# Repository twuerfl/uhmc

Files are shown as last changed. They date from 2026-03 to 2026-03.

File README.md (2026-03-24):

# UHMC – Underfloor Heating Manifold Controller

**UHMC** (Underfloor Heating Manifold Controller) is a modular, ESP32-based controller designed for precise regulation of underfloor heating circuits. It integrates advanced control features while remaining cost-efficient and flexible for home automation setups.

---

## Features

- **Microcontroller:** ESP32-WROOM-32E
- **Connectivity:**
  - Ethernet via LAN8720A **OR** WIFI
  - Optional USB via CP2102N (default not populated to reduce cost)
- **Heating Circuit Control:**
  - 12 heating circuits (loops) total
  - Circuits 11 and 12 share two outputs for double current capacity
- **Driver Hardware:**
  - 2 × TPL7407LAPW motor drivers
  - Each driven via a SN74HC595PWR shift register
- **I²C Expansion:**
  - TCA9548AMRGER I²C multiplexer
  - Supports 8 separate I²C inputs
- **Firmware:** ESPHome

---

## Hardware Overview

| Component | Purpose |
|---|---|
| ESP32-WROOM-32E | Main controller |
| LAN8720A | Ethernet interface |
| CP2102N | Optional USB for programming/debugging |
| TPL7407LAPW | 7-channel motor drivers for valve actuation |
| SN74HC595PWR | Shift registers to extend GPIOs for TPL7407LAPW |
| TCA9548AMRGER | I²C multiplexer for up to 8 I²C inputs |

---

## System Architecture
ESP32

->  SN74HC595  ->   TPL7407LAPW  ->  Heating Circuits 1-12

->  TCA9548AM  ->   I²C Sensors

->  LAN8720A   ->   Ethernet

->  CP2102N    ->   Optional USB

- Heating circuits 11 and 12 are paralleled for higher current capacity.
- ESPHome handles PID control, sensor input, and automation integration.

---

## Features in ESPHome

- Supports up to 12 heating circuits with PWM control
- I²C sensor integration via TCA9548 multiplexer
- Optional integration with Home Assistant
- Ethernet connectivity for remote monitoring and updates
- Modular configuration allowing flexible re-assignment of heating circuits

---

## License

CC BY-NC-SA 4.0
https://creativecommons.org/licenses/by-nc-sa/4.0/

---

## Notes

- USB interface is optional to save cost; populated only if needed.
- Firmware is configured via ESPHome YAML files for easy customization.

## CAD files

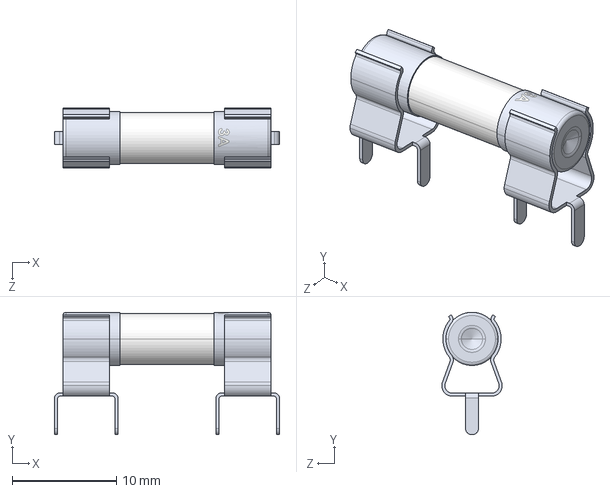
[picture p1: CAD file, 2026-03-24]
step/Fuse Holder.STEP
21.6 x 11.8 x 5.80 mm
Fuse Clip x 2
3A Fuse

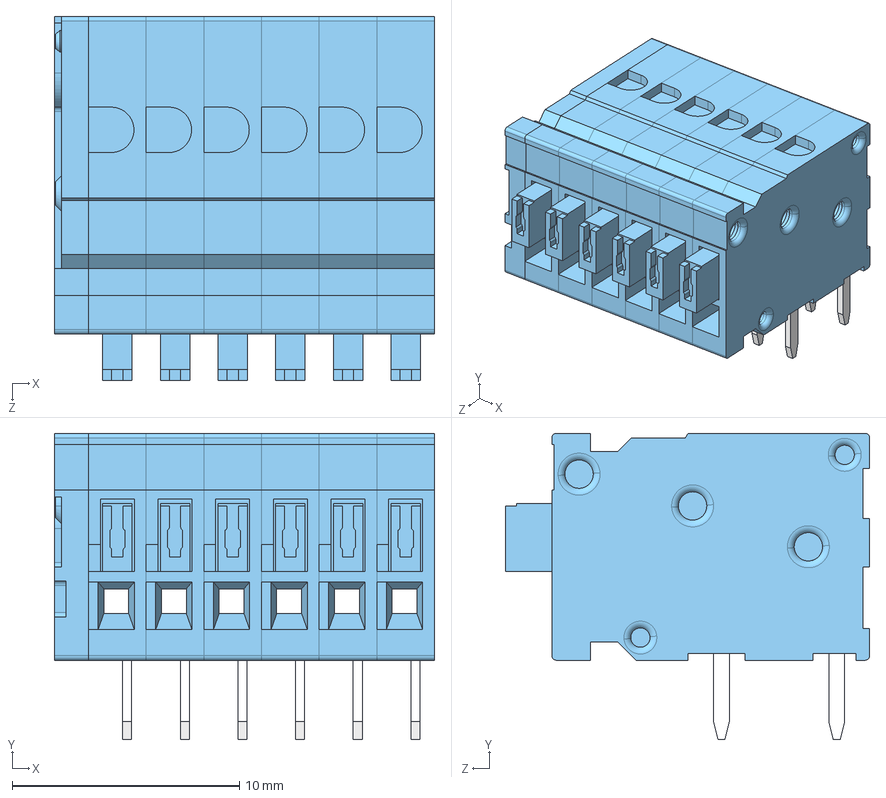
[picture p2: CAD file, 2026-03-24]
step/TBL009-254-06BE-2BE.step
16.7 x 13.5 x 16.1 mm
TBL009-254 - END CAP_Blue
TBL009-254 - BODY_Blue x 6
TBL009-254 - PUSH BUTTON_Blue x 6

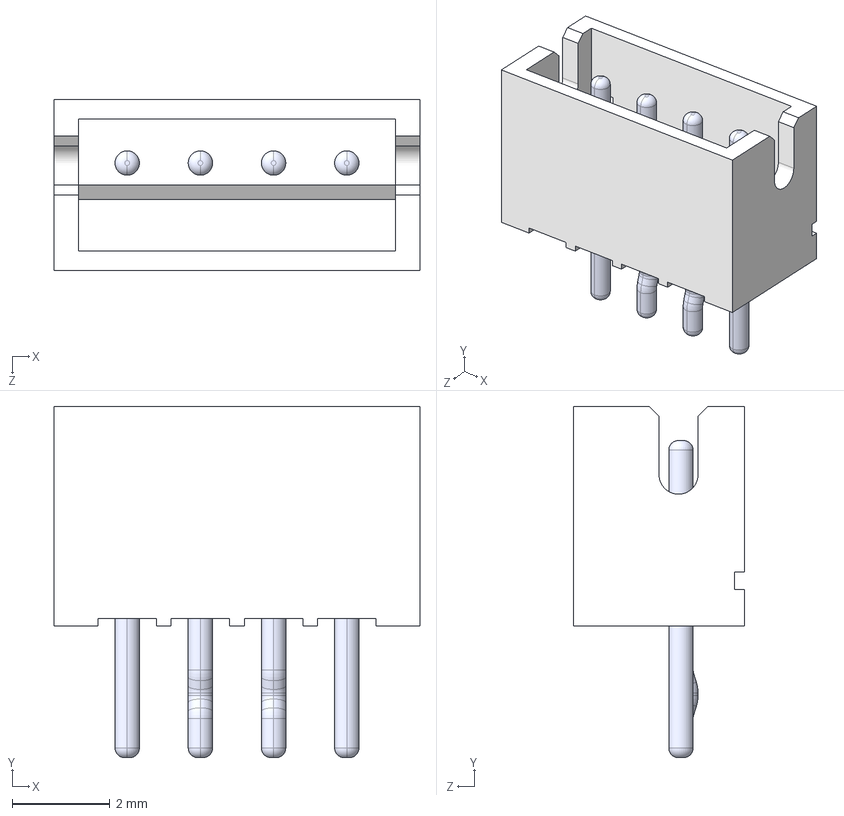
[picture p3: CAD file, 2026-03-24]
step/B4B-ZR--3DModel-STEP-56544.STEP
7.50 x 7.20 x 3.50 mm
BxB-ZR_4
pin_straight x 2
pin_Bent x 2

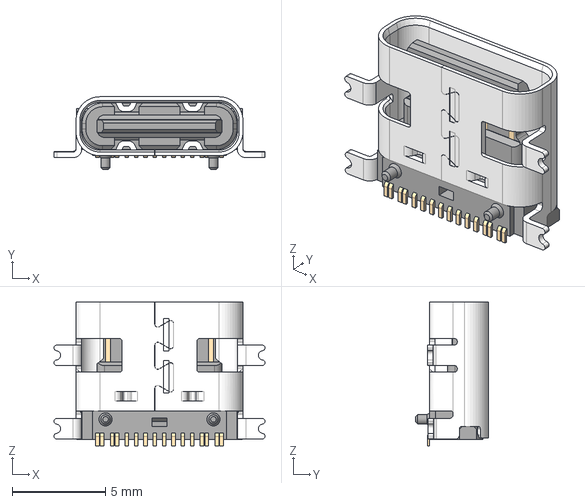
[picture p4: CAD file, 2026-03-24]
step/USB_C_Receptacle_GCT_USB4110.step
11.3 x 3.89 x 7.70 mm

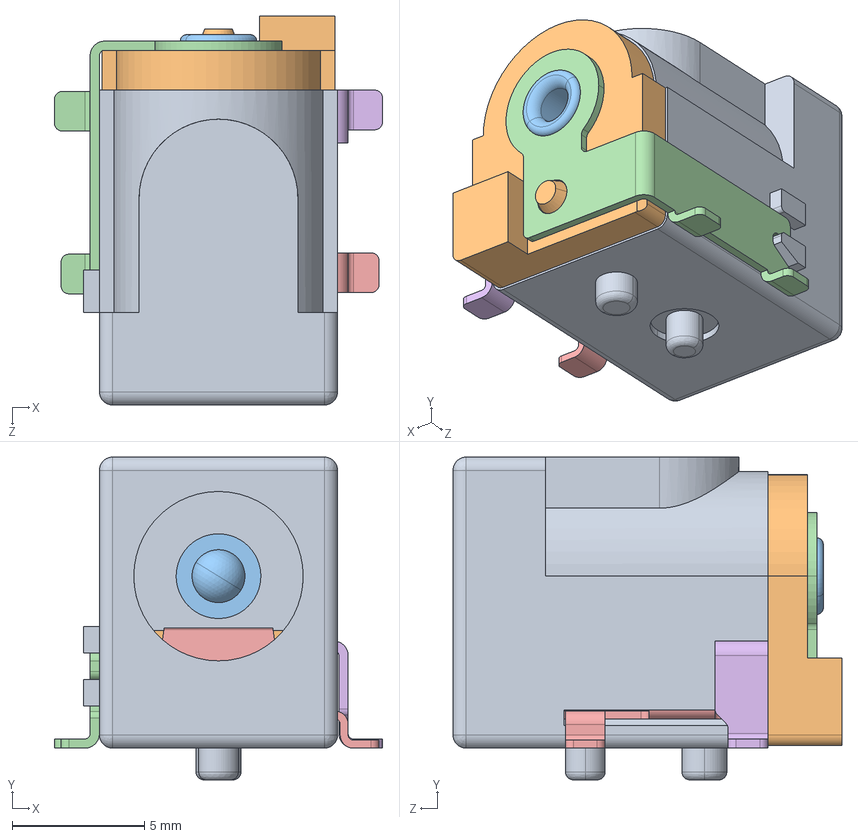
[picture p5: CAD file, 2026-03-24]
step/54-00164.STEP
12.4 x 12.2 x 14.7 mm
54-00164_shell
54-00164_insulator
54-00164_center
54-00164_center contact
54-00164_spring contact
54-00164_shell contact

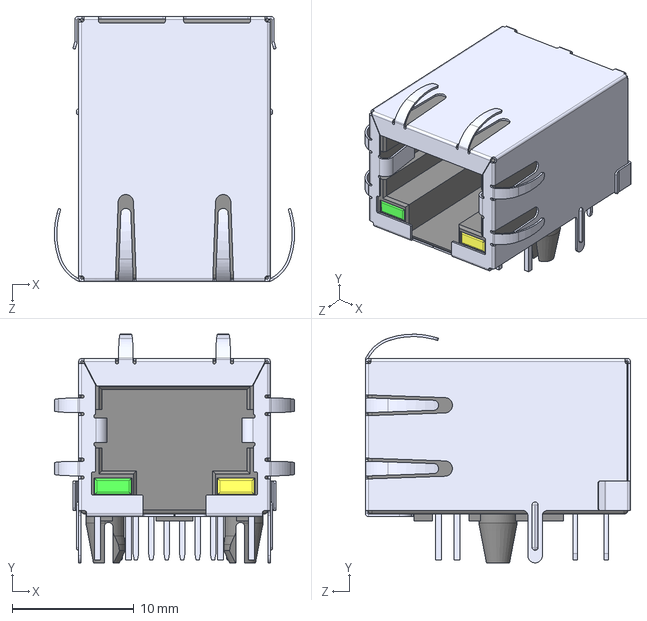
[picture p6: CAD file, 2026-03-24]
step/RJ45_Amphenol_RJMG1BD3B8K1ANR.step
19.7 x 18.8 x 21.8 mm

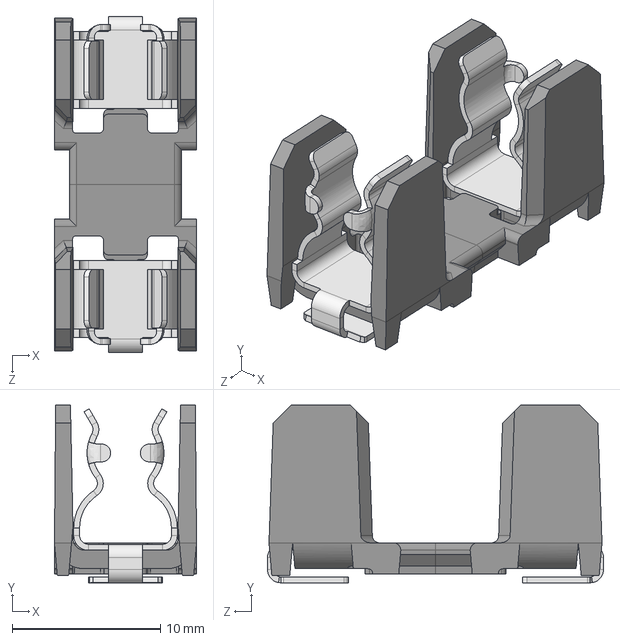
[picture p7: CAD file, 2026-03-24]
step/Fuseholder_Cylinder-5x20mm_Schurter_OGN-SMD_Horizontal_Open.step
9.60 x 12.0 x 22.7 mm

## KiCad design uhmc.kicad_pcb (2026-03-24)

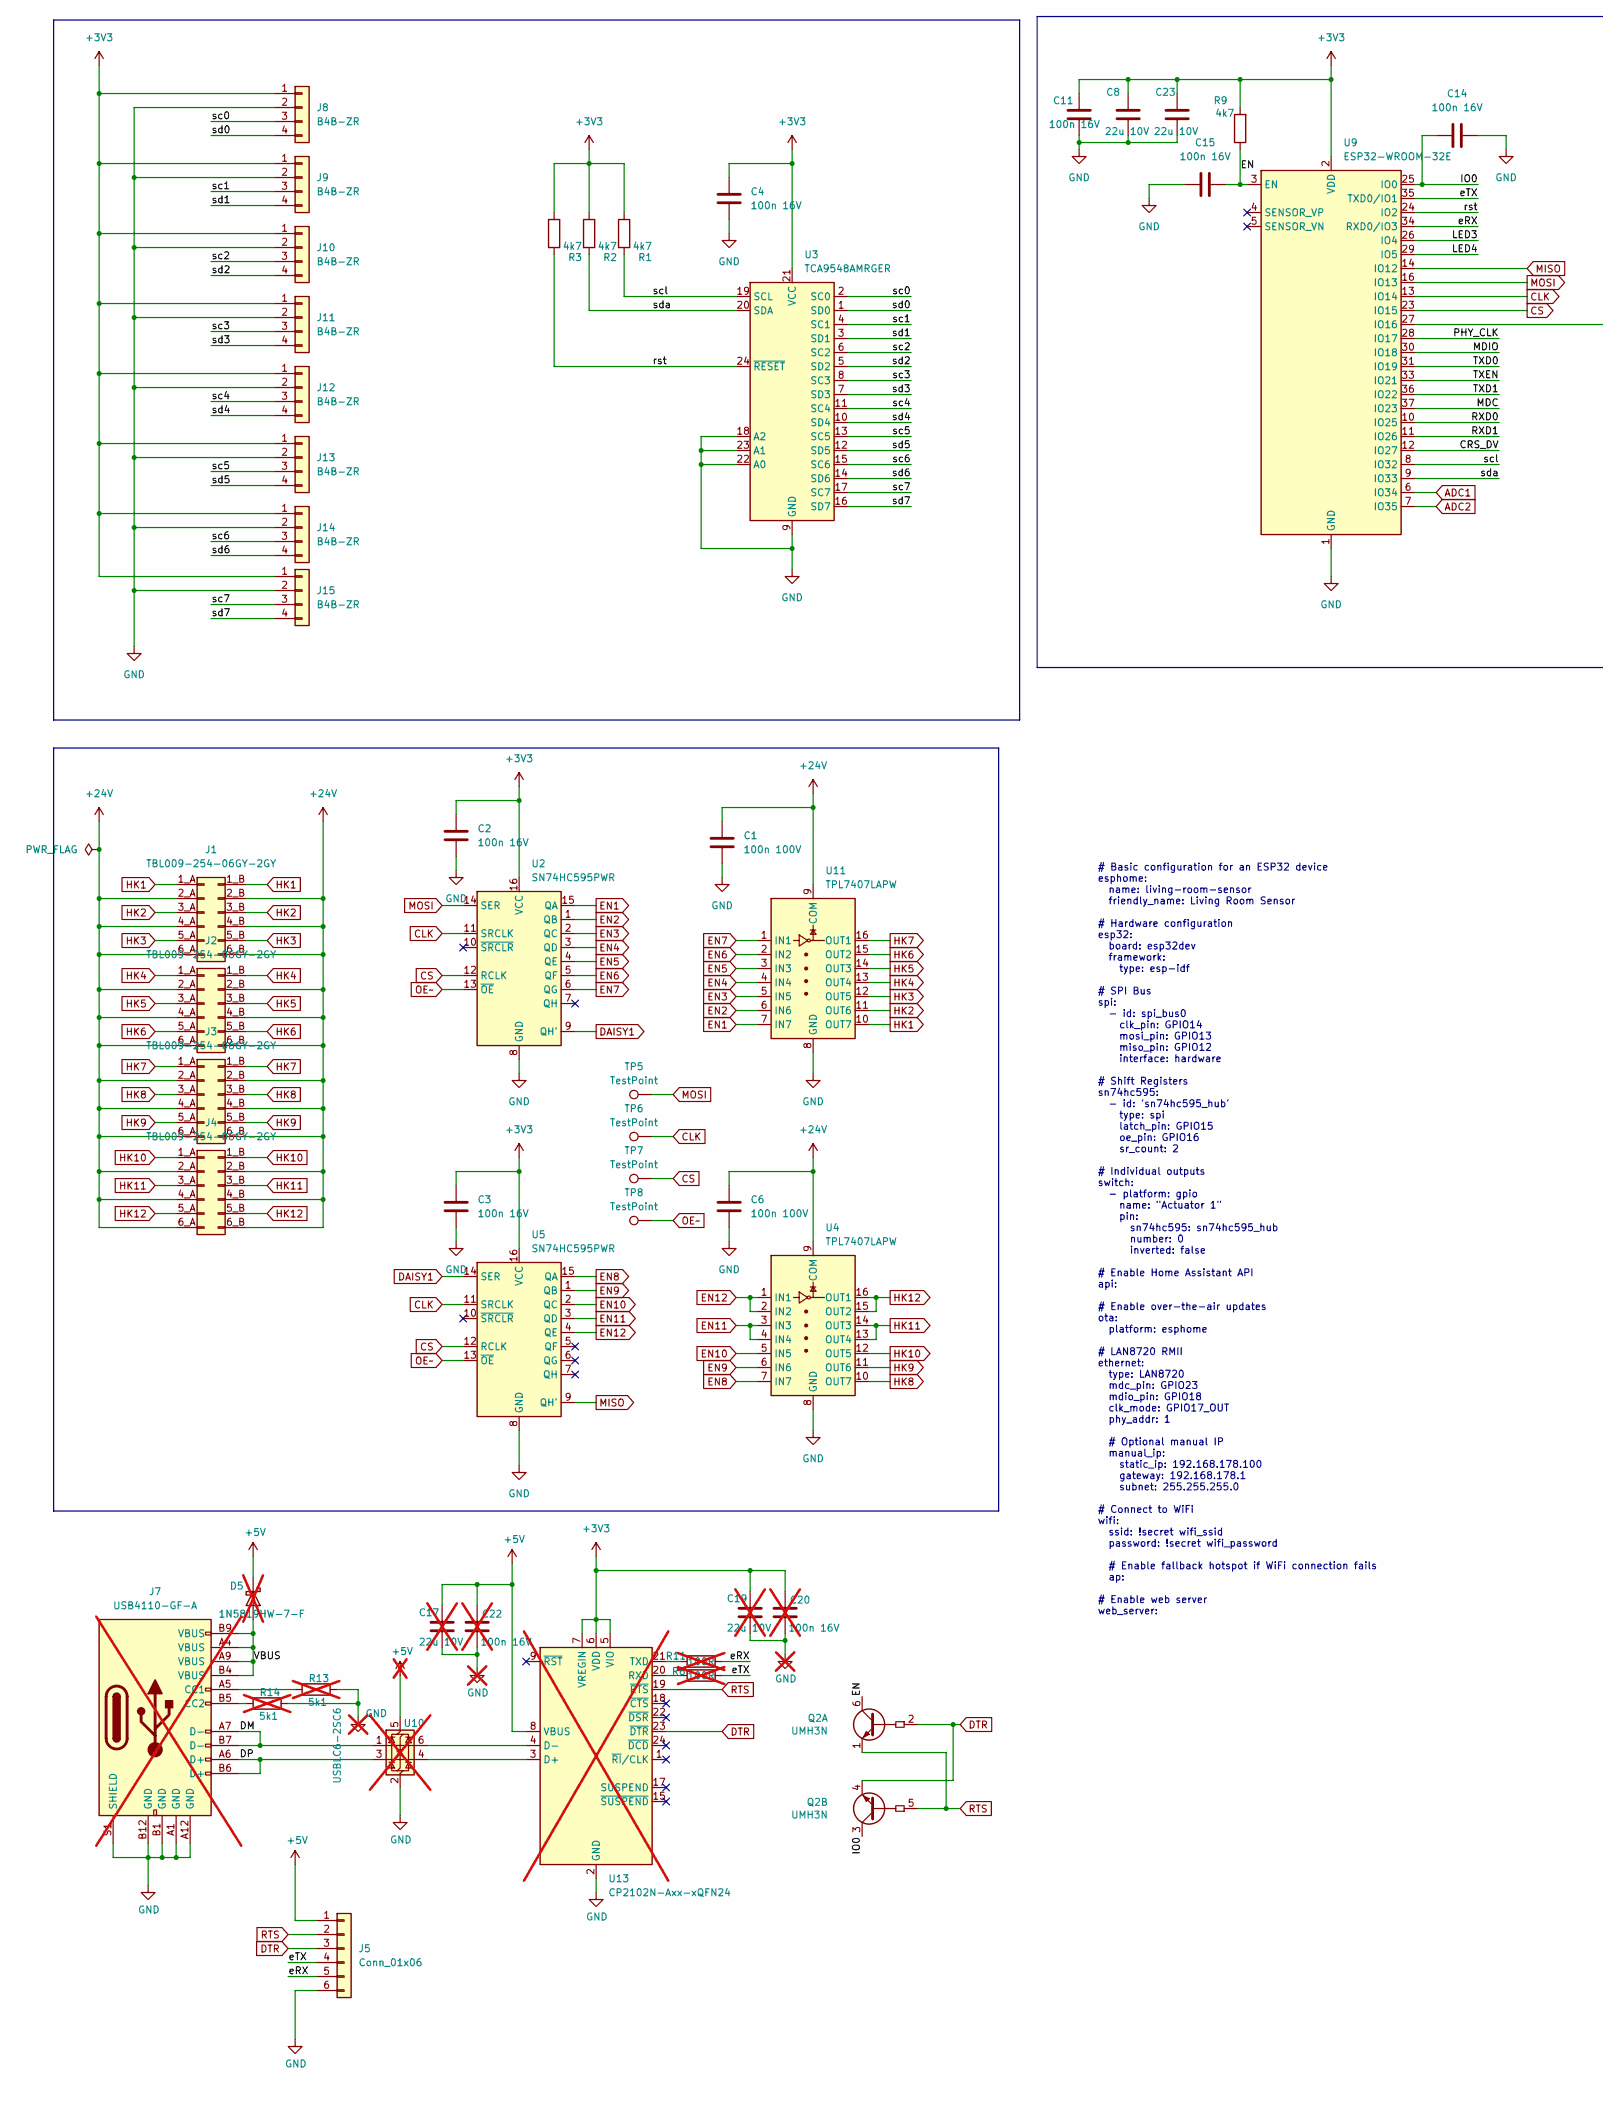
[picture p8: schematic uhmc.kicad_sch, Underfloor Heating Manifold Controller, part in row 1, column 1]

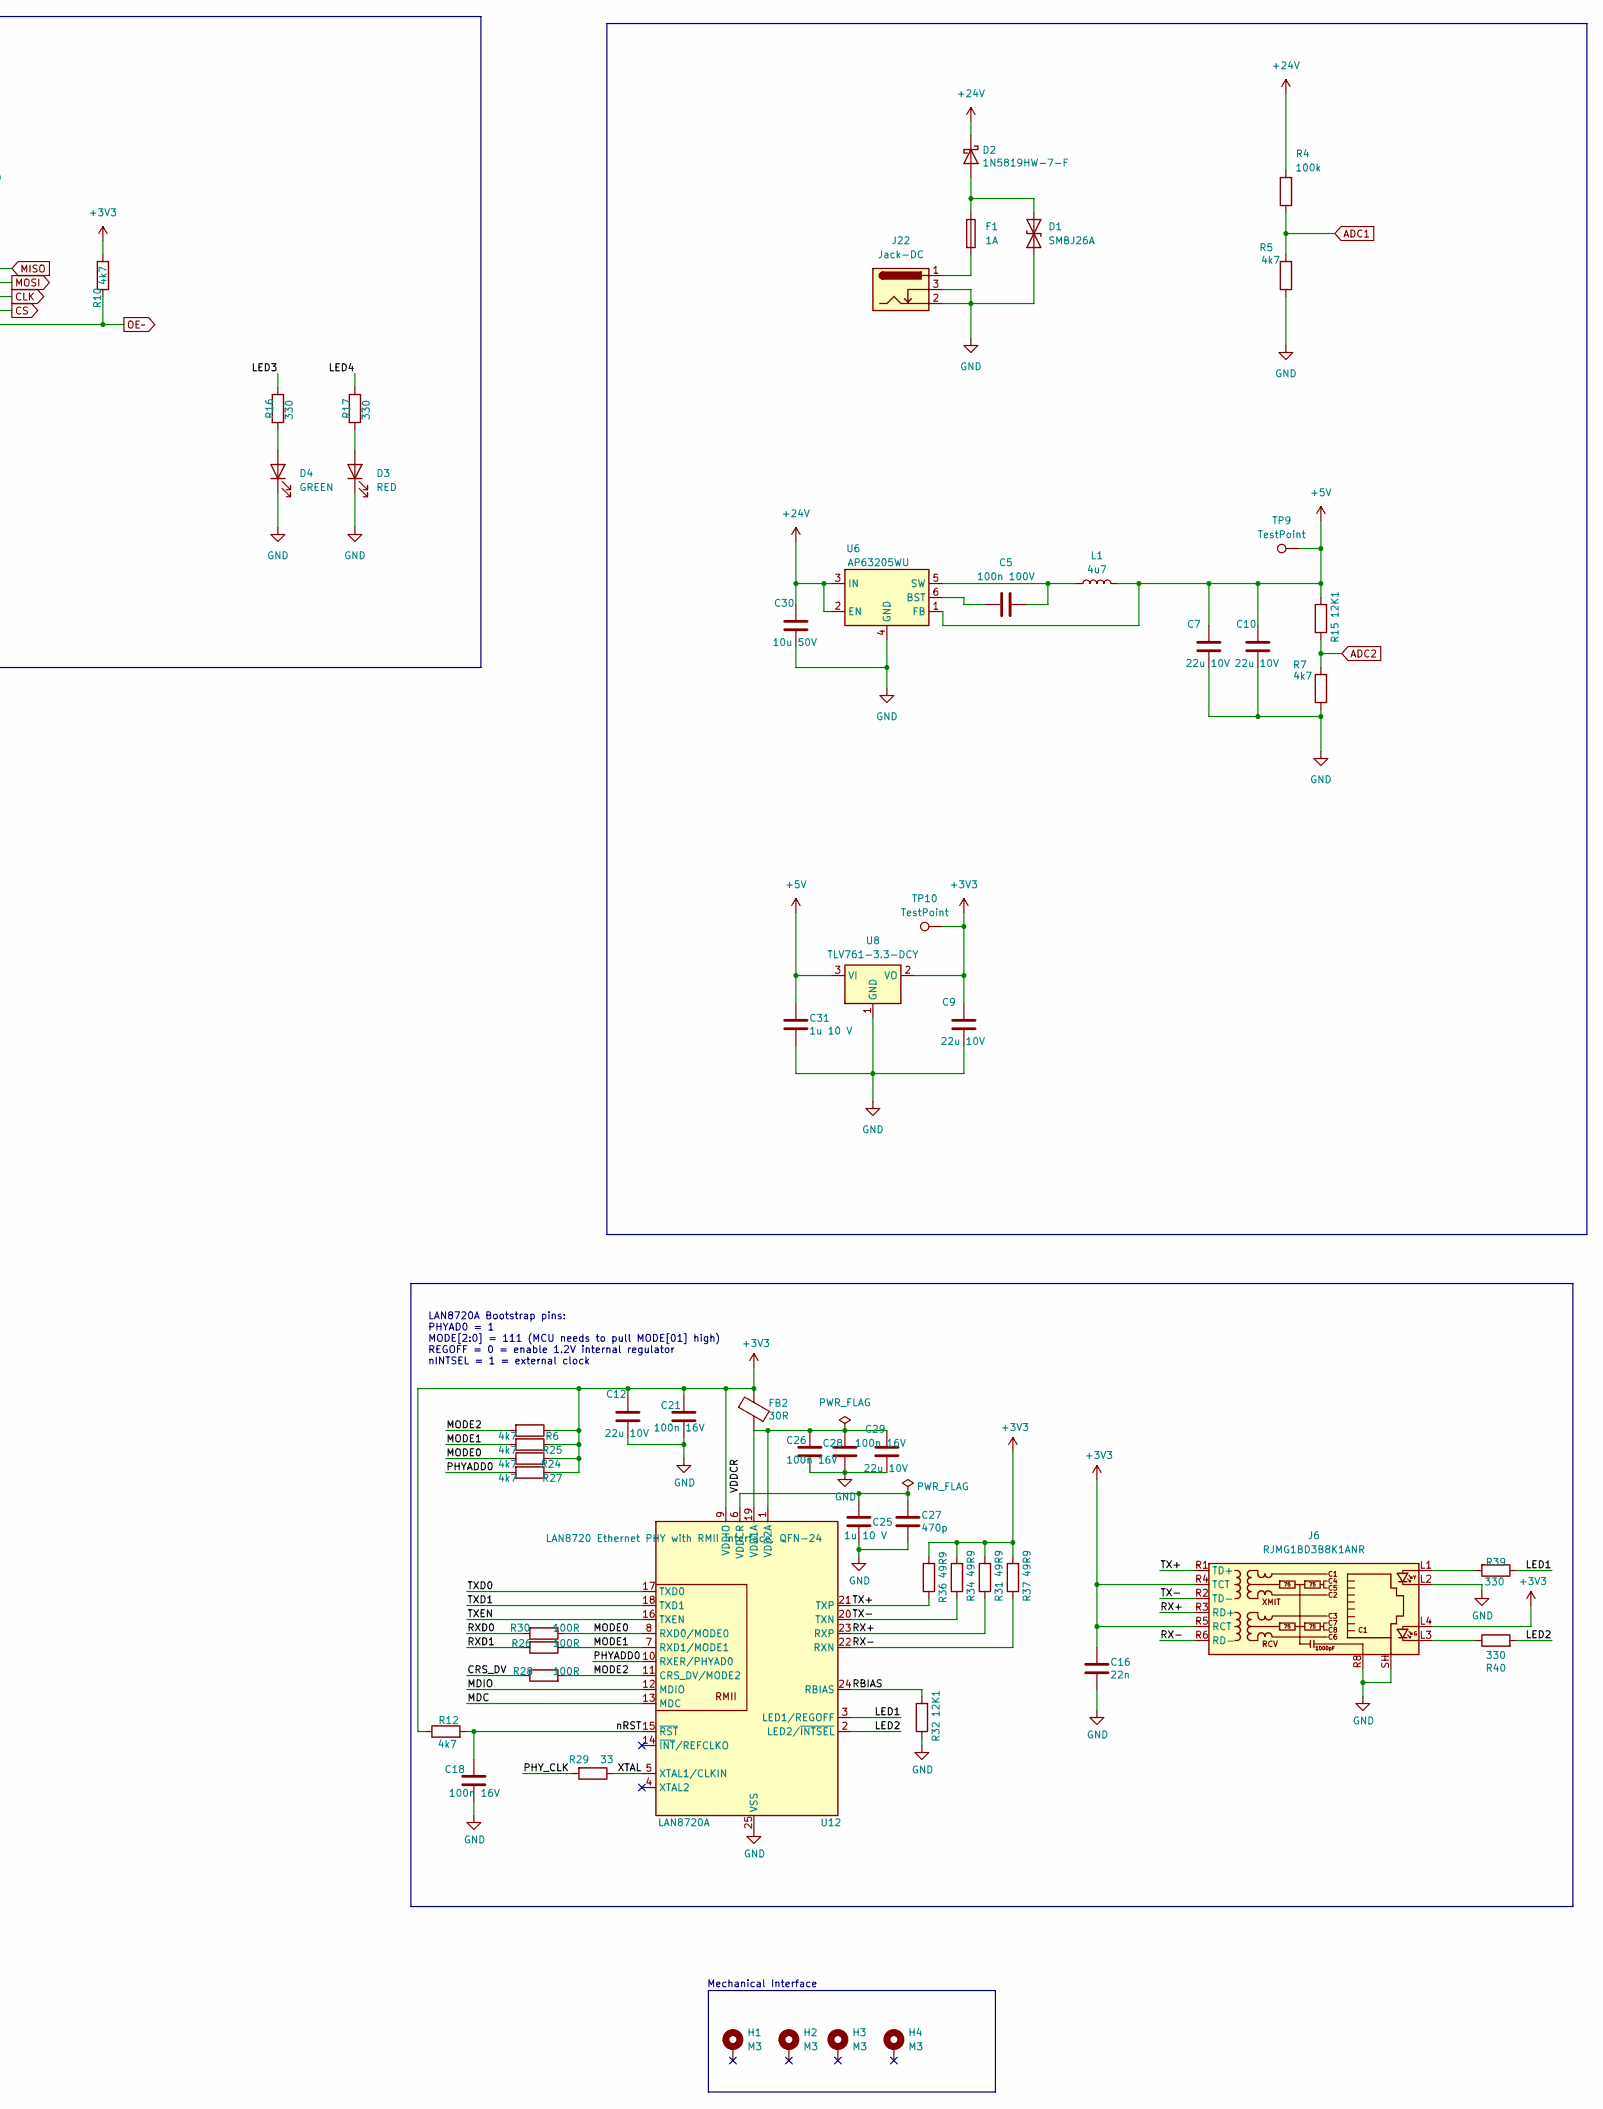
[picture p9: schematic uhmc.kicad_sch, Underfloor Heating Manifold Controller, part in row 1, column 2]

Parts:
C1, C5, C6: 100n 100V; C_0603_1608Metric; MPN CL10B104KC8NNNC
C2, C3, C4, C11, C14, C15, C18, C21, C26, C28: 100n 16V; C_0603_1608Metric; MPN CL10B104KO8NFNC
C7, C8, C9, C10, C12, C23, C29: 22u 10V; C_0603_1608Metric; MPN GRM188R61A226ME15D
C16: 22n; C_0603_1608Metric; MPN CL10B223KB8NNNC
C17, C19: 22u 10V; C_0603_1608Metric; MPN GRM188R61A226ME15D; not fitted
C20, C22: 100n 16V; C_0603_1608Metric; MPN CL10B104KO8NFNC; not fitted
C25, C31: 1u 10 V; C_0603_1608Metric; MPN C0603C105K8RACTU
C27: 470p; C_0603_1608Metric; MPN CL10B102KB8NNNC
C30: 10u 50V; C_1206_3216Metric; MPN CL31A106KBHNNNE
D1: SMBJ26A; D_SMB; MPN SMBJ26A-13-F
D2: 1N5819HW-7-F; D_SOD-123; MPN 1N5819HW-7-F
D3: RED; LED_0603_1608Metric; MPN LTST-C193KRKT-5A
D4: GREEN; LED_0603_1608Metric; MPN LTST-C193KGKT-5A
D5: 1N5819HW-7-F; D_SOD-123; MPN 1N5819HW-7-F; not fitted
F1: 1A; Fuseholder_Clip-5x20mm_Bel_FC-203-22_Lateral_P17.80x5.00mm_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; MPN FC-203
FB2: 30R; L_0603_1608Metric; MPN WLBD1608HCU601TH
H1, H2, H3, H4: M3; MountingHole_3.2mm_M3_ISO7380_Pad
J1, J2, J3, J4: TBL009-254-06GY-2GY; CUI_TBL009-254-06BE-2BE; MPN TBL009-254-06GY-2GY
J5: Conn_01x06; PinHeader_1x06_P1.27mm_Vertical; MPN M50-3530642
J6: RJMG1BD3B8K1ANR; RJ45_Amphenol_RJMG1BD3B8K1ANR; MPN RJMG1BD3B8K1ANR
J7: USB4110-GF-A; USB_C_Receptacle_GCT_USB4110; MPN USB4110-GF-A; not fitted
J8, J9, J10, J11, J12, J13, J14, J15: B4B-ZR; JST_ZH_B4B-ZR_1x04_P1.50mm_Vertical; MPN B4B-ZR
J22: Jack-DC; Tensility 54-00164_SMT_Horizontal; MPN 54-00164
L1: 4u7; L_Bourns-SRN4018; MPN SRN4018-4R7M
Q2: UMH3N; SOT-363_SC-70-6; MPN UMH3NFHATN
R1, R2, R3, R5, R6, R7, R9, R10, R12, R24, R25, R27: 4k7; R_0603_1608Metric; MPN RC0603FR-074K7L
R4: 100k; R_0603_1608Metric; MPN RC0603FR-07100KL
R8, R11: 100R; R_0603_1608Metric; MPN RC0603FR-07100RP; not fitted
R13, R14: 5k1; R_0603_1608Metric; MPN RC0603FR-075K1L; not fitted
R15, R32: 12K1; R_0603_1608Metric; MPN RC0603FR-0712K1L
R16, R17, R39, R40: 330; R_0603_1608Metric; MPN RC0603FR-07330RL
R26, R28, R30: 100R; R_0603_1608Metric; MPN RC0603FR-07100RP
R29: 33; R_0603_1608Metric; MPN RC0603FR-0733RL
R31, R34, R36, R37: 49R9; R_0603_1608Metric; MPN RC0603FR-0749R9L
TP5, TP6, TP7, TP8, TP9, TP10: TestPoint; TestPoint_Pad_D1.0mm
U2, U5: SN74HC595PWR; TSSOP-16_4.4x5mm_P0.65mm; MPN SN74HC595PWR
U3: TCA9548AMRGER; Texas_RGE0024C_VQFN-24-1EP_4x4mm_P0.5mm_EP2.1x2.1mm; MPN TCA9548AMRGER
U4, U11: TPL7407LAPW; TSSOP-16_4.4x5mm_P0.65mm; MPN TPL7407LAPW
U6: AP63205WU; TSOT-23-6; MPN AP63205WU
U8: TLV761-3.3-DCY; SOT-223-3_TabPin2; MPN TLV76133DCYR
U9: ESP32-WROOM-32E; MPN ESP32-WROOM-32E-N8
U10: USBLC6-2SC6; SOT-23-6; MPN USBLC6-2SC6; not fitted
U12: LAN8720A; VQFN-24-1EP_4x4mm_P0.5mm_EP2.5x2.5mm; MPN LAN8720A-CP
U13: CP2102N-Axx-xQFN24; QFN-24-1EP_4x4mm_P0.5mm_EP2.6x2.6mm; MPN CP2102C-A01-GQFN24; not fitted

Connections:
+3V3: C2.2, C3.2, C4.2, C8.1, C9.1, C11.2, C12.1, C16.1, C19.1, C20.1, C21.1, C23.1, FB2.1, J6.L4, J6.R4 (TCT), J6.R5 (RCT), J8.1, J9.1, J10.1, J11.1, J12.1, J13.1, J14.1, J15.1, R1.1, R2.1, R3.1, R6.1, R9.2, R10.2, R12.1, R24.2, R25.1, R27.1, R31.2, R34.2, R36.2, R37.2, TP10.1, U2.16 (VCC), U3.21 (VCC), U5.16 (VCC), U8.2 (VO), U9.2 (VDD), U12.9 (VDDIO), U13.5 (VIO), U13.6 (VDD), U13.7 (VREGIN)
+5V: C7.1, C10.1, C17.1, C22.1, C31.1, D5.1 (K), J5.1, L1.2, R15.2, TP9.1, U6.1 (FB), U8.3 (VI), U10.5 (VBUS), U13.8 (VBUS)
+24V: C1.1, C6.1, C30.1, D2.1 (K), J1.2_A (Pin_2a), J1.2_B (Pin_2b), J1.4_A (Pin_4a), J1.4_B (Pin_4b), J1.6_A (Pin_6a), J1.6_B (Pin_6b), J2.2_A (Pin_2a), J2.2_B (Pin_2b), J2.4_A (Pin_4a), J2.4_B (Pin_4b), J2.6_A (Pin_6a), J2.6_B (Pin_6b), J3.2_A (Pin_2a), J3.2_B (Pin_2b), J3.4_A (Pin_4a), J3.4_B (Pin_4b), J3.6_A (Pin_6a), J3.6_B (Pin_6b), J4.2_A (Pin_2a), J4.2_B (Pin_2b), J4.4_A (Pin_4a), J4.4_B (Pin_4b), J4.6_A (Pin_6a), J4.6_B (Pin_6b), R4.2, U4.9 (COM), U6.2 (EN), U6.3 (IN), U11.9 (COM)
/CRS_DV: R28.1, U9.12 (IO27)
/DM: J7.A7 (D-), J7.B7 (D-), U10.1 (I/O1)
/DP: J7.A6 (D+), J7.B6 (D+), U10.3 (I/O2)
/EN: C15.1, Q2.6 (C1), R9.1, U9.3 (EN)
/IO0: C14.2, Q2.3 (C2), U9.25 (IO0)
/LED1: R39.1, U12.3 (LED1/REGOFF)
/LED2: R40.2, U12.2 (LED2/~INTSEL)
/LED3: R16.1, U9.26 (IO4)
/LED4: R17.1, U9.29 (IO5)
/MDC: U9.37 (IO23), U12.13 (MDC)
/MDIO: U9.30 (IO18), U12.12 (MDIO)
/MODE0: R24.1, R30.1, U12.8 (RXD0/MODE0)
/MODE1: R25.2, R26.1, U12.7 (RXD1/MODE1)
/MODE2: R6.2, R28.2, U12.11 (CRS_DV/MODE2)
/PHYADD0: R27.2, U12.10 (RXER/PHYAD0)
/PHY_CLK: R29.2, U9.28 (IO17)
/RBIAS: R32.2, U12.24 (RBIAS)
/RX+: J6.R3 (RD+), R31.1, U12.23 (RXP)
/RX-: J6.R6 (RD-), R37.1, U12.22 (RXN)
/RXD0: R30.2, U9.10 (IO25)
/RXD1: R26.2, U9.11 (IO26)
/TX+: J6.R1 (TD+), R36.1, U12.21 (TXP)
/TX-: J6.R2 (TD-), R34.1, U12.20 (TXN)
/TXD0: U9.31 (IO19), U12.17 (TXD0)
/TXD1: U9.36 (IO22), U12.18 (TXD1)
/TXEN: U9.33 (IO21), U12.16 (TXEN)
/VBUS: D5.2 (A), J7.A4 (VBUS), J7.A9 (VBUS), J7.B4 (VBUS), J7.B9 (VBUS)
/VDDCR: C25.1, C27.1, U12.6 (VDDCR)
/XTAL: R29.1, U12.5 (XTAL1/CLKIN)
/eRX: J5.5, R11.1, U9.34 (RXD0/IO3)
/eTX: J5.4, R8.1, U9.35 (TXD0/IO1)
/nRST: C18.2, R12.2, U12.15 (~RST)
/rst: R3.2, U3.24 (~RESET), U9.24 (IO2)
/sc0: J8.3, U3.2 (SC0)
/sc1: J9.3, U3.4 (SC1)
/sc2: J10.3, U3.6 (SC2)
/sc3: J11.3, U3.8 (SC3)
/sc4: J12.3, U3.11 (SC4)
/sc5: J13.3, U3.13 (SC5)
/sc6: J14.3, U3.15 (SC6)
/sc7: J15.3, U3.17 (SC7)
/scl: R1.2, U3.19 (SCL), U9.8 (IO32)
/sd0: J8.4, U3.1 (SD0)
/sd1: J9.4, U3.3 (SD1)
/sd2: J10.4, U3.5 (SD2)
/sd3: J11.4, U3.7 (SD3)
/sd4: J12.4, U3.10 (SD4)
/sd5: J13.4, U3.12 (SD5)
/sd6: J14.4, U3.14 (SD6)
/sd7: J15.4, U3.16 (SD7)
/sda: R2.2, U3.20 (SDA), U9.9 (IO33)
ADC1: R4.1, R5.2, U9.6 (IO34)
ADC2: R7.2, R15.1, U9.7 (IO35)
CLK: TP6.1, U2.11 (SRCLK), U5.11 (SRCLK), U9.13 (IO14)
CS: TP7.1, U2.12 (RCLK), U5.12 (RCLK), U9.23 (IO15)
DAISY1: U2.9 (QH'), U5.14 (SER)
DTR: J5.3, Q2.2 (B1), Q2.4 (E2), U13.23 (~DTR)
EN1: U2.15 (QA), U11.7 (IN7)
EN2: U2.1 (QB), U11.6 (IN6)
EN3: U2.2 (QC), U11.5 (IN5)
EN4: U2.3 (QD), U11.4 (IN4)
EN5: U2.4 (QE), U11.3 (IN3)
EN6: U2.5 (QF), U11.2 (IN2)
EN7: U2.6 (QG), U11.1 (IN1)
EN8: U4.7 (IN7), U5.15 (QA)
EN9: U4.6 (IN6), U5.1 (QB)
EN10: U4.5 (IN5), U5.2 (QC)
EN11: U4.3 (IN3), U4.4 (IN4), U5.3 (QD)
EN12: U4.1 (IN1), U4.2 (IN2), U5.4 (QE)
GND: C1.2, C2.1, C3.1, C4.1, C6.2, C7.2, C8.2, C9.2, C10.2, C11.1, C12.2, C14.1, C15.2, C16.2, C17.2, C18.1, C19.2, C20.2, C21.2, C22.2, C23.2, C25.2, C26.1, C27.2, C28.1, C29.2, C30.2, C31.2, D1.1 (A1), D3.1 (K), D4.1 (K), J5.6, J6.L2, J6.R8, J6.SH, J7.A1 (GND), J7.A12 (GND), J7.B1 (GND), J7.B12 (GND), J7.S1 (SHIELD), J8.2, J9.2, J10.2, J11.2, J12.2, J13.2, J14.2, J15.2, J22.2, J22.3, R5.1, R7.1, R13.2, R14.2, R32.1, U2.8 (GND), U3.9 (GND), U3.18 (A2), U3.22 (A0), U3.23 (A1), U4.8 (GND), U5.8 (GND), U6.4 (GND), U8.1 (GND), U9.1 (GND), U9.15 (GND), U9.38 (GND), U9.39 (GND), U10.2 (GND), U11.8 (GND), U12.25 (VSS), U13.2 (GND), U13.25 (GND)
HK1: J1.1_A (Pin_1a), J1.1_B (Pin_1b), U11.10 (OUT7)
HK2: J1.3_A (Pin_3a), J1.3_B (Pin_3b), U11.11 (OUT6)
HK3: J1.5_A (Pin_5a), J1.5_B (Pin_5b), U11.12 (OUT5)
HK4: J2.1_A (Pin_1a), J2.1_B (Pin_1b), U11.13 (OUT4)
HK5: J2.3_A (Pin_3a), J2.3_B (Pin_3b), U11.14 (OUT3)
HK6: J2.5_A (Pin_5a), J2.5_B (Pin_5b), U11.15 (OUT2)
HK7: J3.1_A (Pin_1a), J3.1_B (Pin_1b), U11.16 (OUT1)
HK8: J3.3_A (Pin_3a), J3.3_B (Pin_3b), U4.10 (OUT7)
HK9: J3.5_A (Pin_5a), J3.5_B (Pin_5b), U4.11 (OUT6)
HK10: J4.1_A (Pin_1a), J4.1_B (Pin_1b), U4.12 (OUT5)
HK11: J4.3_A (Pin_3a), J4.3_B (Pin_3b), U4.13 (OUT4), U4.14 (OUT3)
HK12: J4.5_A (Pin_5a), J4.5_B (Pin_5b), U4.15 (OUT2), U4.16 (OUT1)
MISO: U5.9 (QH'), U9.14 (IO12)
MOSI: TP5.1, U2.14 (SER), U9.16 (IO13)
unnamed: D1.2 (A2), D2.2 (A), F1.1
unnamed: D3.2 (A), R17.2
unnamed: D4.2 (A), R16.2
unnamed: F1.2, J22.1
unnamed: J6.L1, R39.2
unnamed: J6.L3, R40.1
unnamed: J7.A5 (CC1), R13.1
unnamed: J7.B5 (CC2), R14.1
unnamed: C5.2, U6.6 (BST)
unnamed: C5.1, L1.1, U6.5 (SW)
unnamed: C26.2, C28.2, C29.1, FB2.2, U12.1 (VDD2A), U12.19 (VDD1A)
unnamed: U10.4 (I/O2), U13.3 (D+)
unnamed: U10.6 (I/O1), U13.4 (D-)
unnamed: R8.2, U13.20 (RXD)
unnamed: R11.2, U13.21 (TXD)
OE~: R10.1, TP8.1, U2.13 (~OE), U5.13 (~OE), U9.27 (IO16)
RTS: J5.2, Q2.1 (E1), Q2.5 (B2), U13.19 (~RTS)

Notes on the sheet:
# Basic configuration for an ESP32 device esphome: name: living-room-sensor friendly_name: Living Room Sensor # Hardware configuration esp32: board: esp32dev framework: type: esp-idf # SPI Bus spi: - id: spi_bus0 clk_pin: GPIO14 mosi_pin: GPIO13 miso_pin: GPIO12 interface: hardware # Shift Register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
LAN8720A Bootstrap pins: PHYAD0 = 1 MODE[2:0] = 111 (MCU needs to pull MODE[01] high) REGOFF = 0 = enable 1.2V internal regulator nINTSEL = 1 = external clock
Mechanical Interface

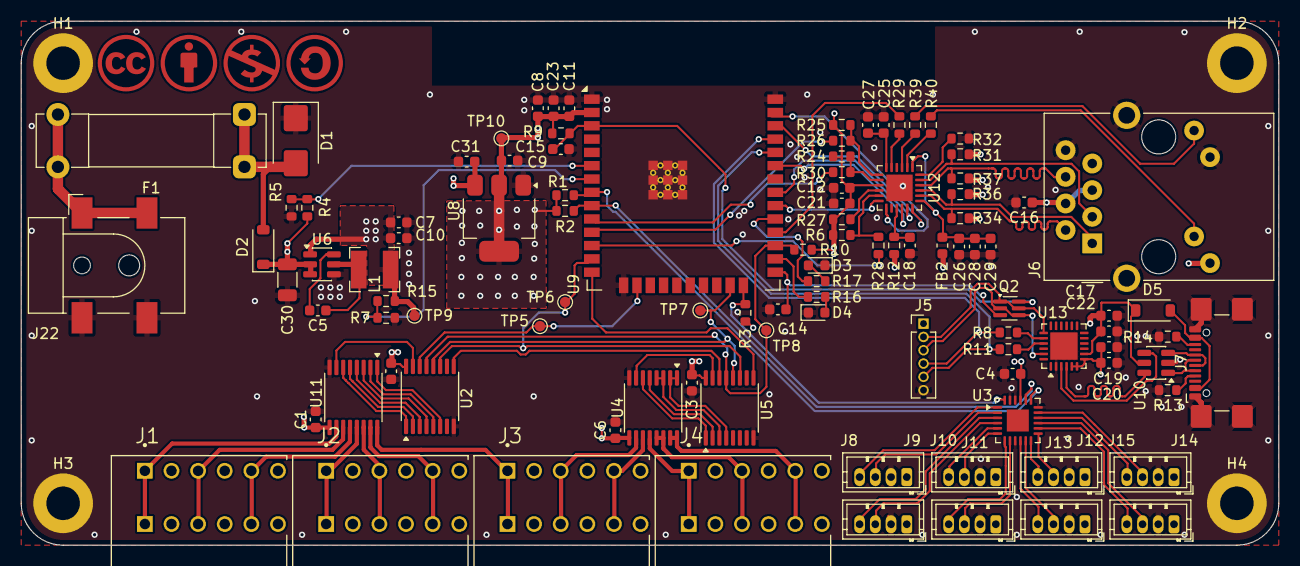
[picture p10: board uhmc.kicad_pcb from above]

Board: 4 copper layers, 120.0 x 50.0 mm, 106 parts (0 on the bottom side), 104 nets.

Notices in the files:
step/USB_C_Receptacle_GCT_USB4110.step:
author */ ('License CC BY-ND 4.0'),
